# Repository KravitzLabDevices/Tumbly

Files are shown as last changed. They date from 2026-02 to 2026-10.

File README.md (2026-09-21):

# Tumbly
<p align="center">
  Tumbly timelapse
</p>
An Arduino library for the Tumbly device, a time-restricted feeding device. 

**Hardware:** Adafruit Feather M0, OLED FeatherWing (SH1107), RTC FeatherWing, SD card, Servo  

See the [Wiki](https://github.com/KravitzLabDevices/Tumbly/wiki) for build instructions.

Based on the [Tumble Feeder](https://pubmed.ncbi.nlm.nih.gov/40541188/).

## License

GPL-3.0

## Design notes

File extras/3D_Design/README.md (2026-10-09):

3D print the four .stl files in this folder (currently for Allentown MAX caging):  


Editable TinkerCAD design is [here](https://www.tinkercad.com/things/fWfIexFPPOE-tumblycurrent100926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).

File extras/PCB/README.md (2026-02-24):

Order the custom PCB (you can download BRD and SCH files from the extras directory and have this made anywhere, or click this link to order the PCB from OshPark)



Top  <br>

Bottom

Assembly instructions:  
1) Populate the custom PCB:  
  

2) Add stacking headers to the Adafruit DS3231 RTC board and Adafruit M0 Adalogger
  

3) Stack the four boards together - that's it!



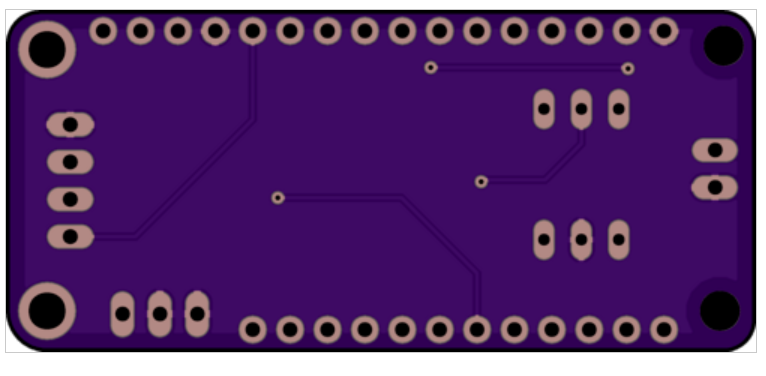
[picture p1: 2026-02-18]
extras/PCB/Bottom.png

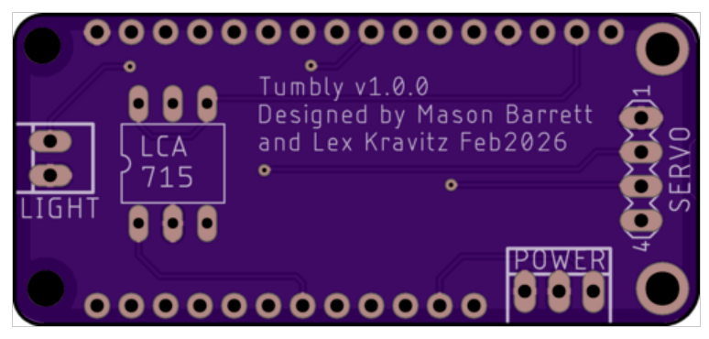
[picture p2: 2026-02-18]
extras/PCB/Top.png

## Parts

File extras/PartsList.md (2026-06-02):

## <a href="https://docs.google.com/spreadsheets/d/1O0kQEswAetQ5PXhv6P8ZYKxMUGYi77xnT9NAyXGhbck/edit?usp=sharing">Click here</a> for Tumbly parts list.
<br>
Updated 05/26/2026

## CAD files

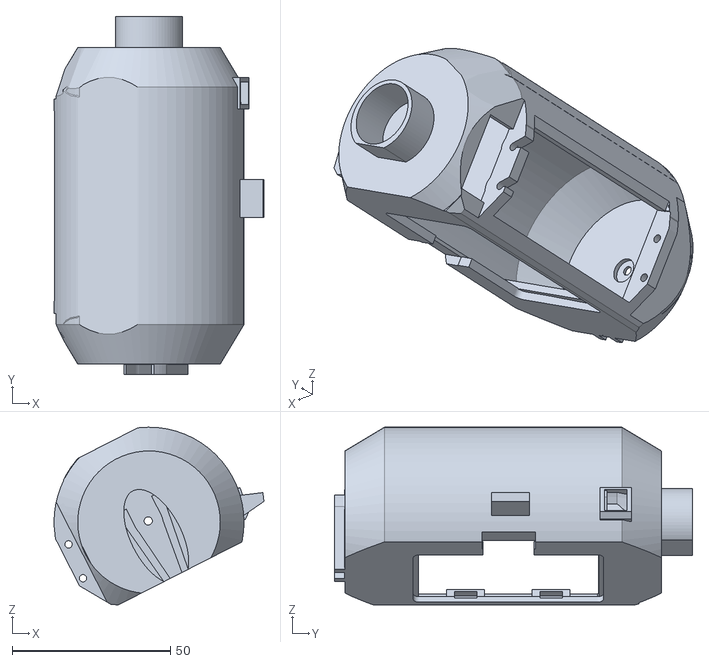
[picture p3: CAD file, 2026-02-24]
extras/3D_Design/Tumbly_Hopper.stl
66.3 x 113.1 x 56.1

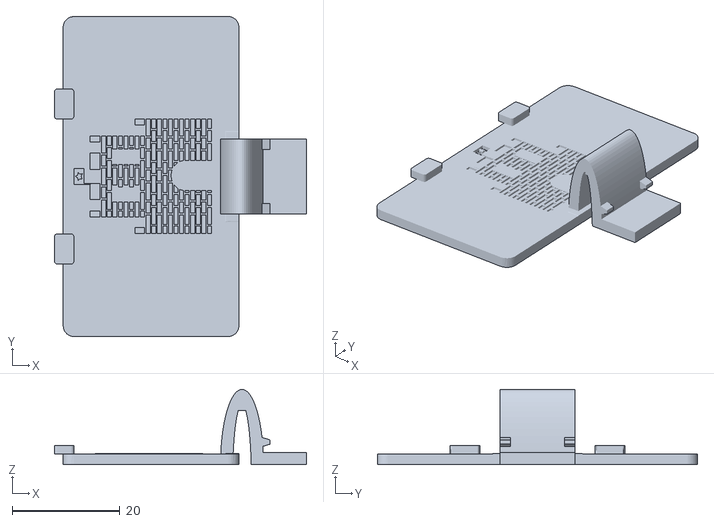
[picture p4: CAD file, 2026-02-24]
extras/3D_Design/Tumbly_Door.stl
46.9 x 59.5 x 14.0

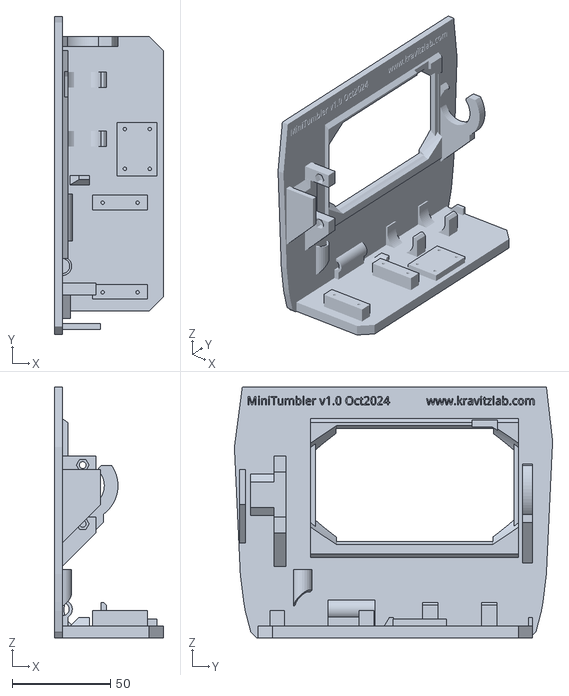
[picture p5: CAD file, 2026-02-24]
extras/3D_Design/Tumbly_Base.stl
55.5 x 162.3 x 128.0

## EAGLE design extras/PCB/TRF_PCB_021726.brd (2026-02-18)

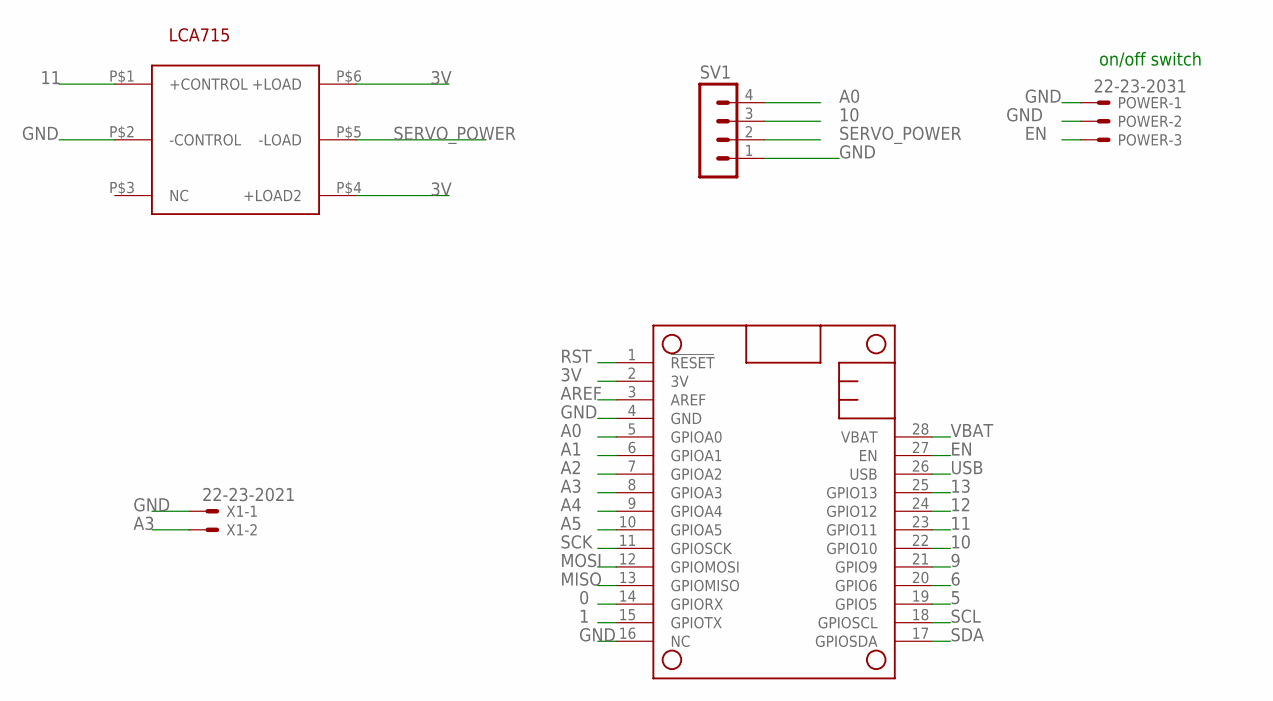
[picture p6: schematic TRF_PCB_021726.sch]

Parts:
MS2: MICROSHIELD_NODIM; MICROSHIELD_DIM
POWER: 22-23-2031
SSR3: LCA715S; LCA7XX
SV1: MA04-1
X1: 22-23-2021

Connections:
0: MS2.14 (GPIORX)
1: MS2.15 (GPIOTX)
3V: MS2.2 (3V), SSR3.P$4 (+LOAD2), SSR3.P$6 (+LOAD)
5: MS2.19 (GPIO5)
6: MS2.20 (GPIO6)
9: MS2.21 (GPIO9)
10: MS2.22 (GPIO10), SV1.3
11: MS2.23 (GPIO11), SSR3.P$1 (+CONTROL)
12: MS2.24 (GPIO12)
13: MS2.25 (GPIO13)
A0: MS2.5 (GPIOA0), SV1.4
A1: MS2.6 (GPIOA1)
A2: MS2.7 (GPIOA2)
A3: MS2.8 (GPIOA3), X1.2
A4: MS2.9 (GPIOA4)
A5: MS2.10 (GPIOA5)
AREF: MS2.3 (AREF)
EN: MS2.27 (EN), POWER.3
GND: MS2.4 (GND), MS2.16 (NC), POWER.1, POWER.2, SSR3.P$2 (-CONTROL), SV1.1, X1.1
MISO: MS2.13 (GPIOMISO)
MOSI: MS2.12 (GPIOMOSI)
RST: MS2.1 (!RESET)
SCK: MS2.11 (GPIOSCK)
SCL: MS2.18 (GPIOSCL)
SDA: MS2.17 (GPIOSDA)
SERVO_POWER: SSR3.P$5 (-LOAD), SV1.2
USB: MS2.26 (USB)
VBAT: MS2.28 (VBAT)

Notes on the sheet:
on/off switch

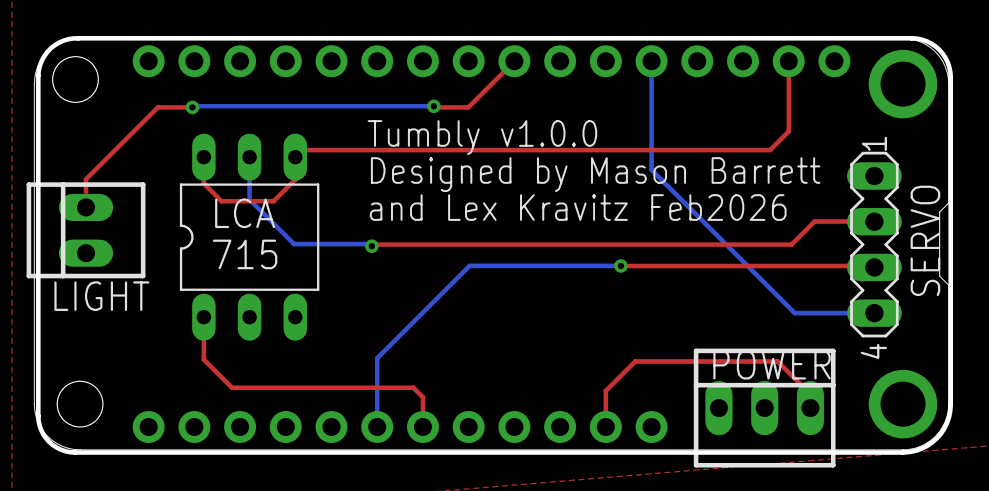
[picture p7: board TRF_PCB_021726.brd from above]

Board: 2 copper layers, 50.7 x 23.0 mm, 5 parts (0 on the bottom side), 8 nets.

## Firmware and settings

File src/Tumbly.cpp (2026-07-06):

/********************************************************
  Tumbly - Library
  Copyright (c) 2024 Lex Kravitz, Mason Barrett
  Released under GPL-3.0
 ********************************************************/

#include "Tumbly.h"
#include <math.h>

/*==============================================================================
  STARTUP ANIMATION
  File-scope drawing helpers for the boot animation (a mouse tipping a "TUMBLY"
  block into a cage of food). Not part of the class API. Coordinates assume the
  128x64 landscape orientation set up in begin().
==============================================================================*/

// Scatter of food pellets piled in the bottom-left corner.
static void _animFood(Adafruit_SH1107& d) {
  d.fillCircle( 7,62,3,SH110X_WHITE); d.fillCircle(16,63,3,SH110X_WHITE);
  d.fillCircle(25,61,3,SH110X_WHITE); d.fillCircle(34,63,3,SH110X_WHITE);
  d.fillCircle(42,62,3,SH110X_WHITE); d.fillCircle(11,55,3,SH110X_WHITE);
  d.fillCircle(21,54,3,SH110X_WHITE); d.fillCircle(30,56,3,SH110X_WHITE);
  d.fillCircle(39,54,3,SH110X_WHITE); d.fillCircle(15,48,3,SH110X_WHITE);
  d.fillCircle(26,47,3,SH110X_WHITE); d.fillCircle(36,49,2,SH110X_WHITE);
  d.fillCircle(19,41,3,SH110X_WHITE); d.fillCircle(29,40,2,SH110X_WHITE);
  d.fillCircle(24,35,2,SH110X_WHITE);
}

// Cage bars; cellY slides the cage in vertically during the animation.
static void _animCell(Adafruit_SH1107& d, int cellY) {
  int boxTop    = max(cellY, 0);
  int boxBottom = min(cellY + 43, 63);
  if (boxBottom < boxTop) return;
  if (cellY >= 0 && cellY <= 61)
    d.fillRect(2, cellY, 46, 3, SH110X_WHITE);
  int barXs[] = {2, 13, 24, 35, 46};
  int barLen  = boxBottom - boxTop + 1;
  for (int i = 0; i < 5; i++) {
    d.drawFastVLine(barXs[i],     boxTop, barLen, SH110X_WHITE);
    d.drawFastVLine(barXs[i] + 1, boxTop, barLen, SH110X_WHITE);
  }
}

// The mouse; ox shifts it horizontally so it can walk in from the right.
static void _animMouse(Adafruit_SH1107& d, int ox) {
  // Body — scanline horizontal ellipse
  { const int ecx=95+ox, ecy=60, ra=17, rb=9;
    for (int y=max(0,ecy-rb); y<=min(63,ecy+rb); y++) {
      float dy=(float)(y-ecy);
      int   dx=(int)(ra*sqrtf(1.0f-(dy*dy)/((float)(rb*rb))));
      d.drawFastHLine(ecx-dx, y, 2*dx+1, SH110X_WHITE);
    }
  }
  d.fillCircle(81+ox,50,7,SH110X_WHITE);                          // head
  d.fillCircle(86+ox,43,4,SH110X_WHITE);                          // ear
  d.fillTriangle(68+ox,50,74+ox,46,74+ox,54,SH110X_WHITE);        // nose
  d.fillCircle(82+ox,47,2,SH110X_BLACK);                          // eye
  d.drawLine(71+ox,49,63+ox,45,SH110X_WHITE);                     // whiskers
  d.drawLine(71+ox,51,62+ox,51,SH110X_WHITE);
  d.drawLine(71+ox,53,63+ox,57,SH110X_WHITE);
  { const int tcx=115+ox, tcy=59, tr=9;                           // tail arc
    for (int a=180; a>0; a-=15) {
      float r1=a*3.14159265f/180.0f, r2=(a-15)*3.14159265f/180.0f;
      d.drawLine(tcx+(int)(tr*cosf(r1)+0.5f), tcy-(int)(tr*sinf(r1)+0.5f),
                 tcx+(int)(tr*cosf(r2)+0.5f), tcy-(int)(tr*sinf(r2)+0.5f),
                 SH110X_WHITE);
    }
  }
}

// The "TUMBLY" text block rendered from a 1-bit canvas; startX slides it in and
// a small per-row lean gives it a tipping look.
static void _animTumbly(Adafruit_SH1107& d, GFXcanvas1& canvas, int startX) {
  if (startX >= 128) return;
  for (int cy=0; cy<20; cy++) {
    int lean=(5*max(0,16-cy))/16;
    for (int cx=0; cx<96; cx++) {
      if (canvas.getPixel(cx,cy)) {
        int dx=startX+cx+lean;
        if (dx>=0 && dx<128) d.drawPixel(dx, cy, SH110X_WHITE);
      }
    }
  }
  int ls=max(0,startX);
  d.drawFastHLine(ls,  0, 128-ls, SH110X_WHITE);
  d.drawFastHLine(ls, 20, 128-ls, SH110X_WHITE);
}

// Compose one full frame from the four elements and push it to the panel.
static void _animFrame(Adafruit_SH1107& d, GFXcanvas1& canvas, int tx, int cy, int mx) {
  d.clearDisplay();
  _animFood(d); _animCell(d,cy); _animMouse(d,mx); _animTumbly(d,canvas,tx);
  d.display();
}

// Play the whole sequence: block slides in, mouse tips it, it falls and bounces.
static void _animPlay(Adafruit_SH1107& d) {
  GFXcanvas1 canvas(96, 20);
  canvas.fillScreen(0); canvas.setTextSize(2);
  canvas.setTextColor(1); canvas.setCursor(2,2);
  canvas.print("TUMBLY");
  delay(100);

  _animFrame(d,canvas,128,-50,128); delay(200);
  _animFrame(d,canvas, 95,-50,128); delay(250);
  _animFrame(d,canvas, 75,-50,128); delay(250);
  _animFrame(d,canvas, 62,-50,128); delay(250);
  _animFrame(d,canvas, 50,-50,128); delay(200);

  _animFrame(d,canvas,50,-50, 50); delay(115);
  _animFrame(d,canvas,50,-41, 25); delay(100);
  _animFrame(d,canvas,50,-29,  0); delay(80);
  _animFrame(d,canvas,50,-14,  0); delay(60);
  _animFrame(d,canvas,50,  2,  0); delay(42);
  _animFrame(d,canvas,50, 13,  0); delay(30);
  _animFrame(d,canvas,50, 19,  0); delay(22);
  _animFrame(d,canvas,50, 21,  0); delay(18);  // slam!
  _animFrame(d,canvas,50, 14,  0); delay(65);  // bounce
  _animFrame(d,canvas,50, 21,  0); delay(55);
  _animFrame(d,canvas,50, 17,  0); delay(50);
  _animFrame(d,canvas,50, 21,  0); delay(100); // hold
}

/*==============================================================================
  STATIC STATE & CALLBACKS
  A single active instance pointer lets the C-style RTC/wake callbacks reach the
  object. _wokenByButton is set from the sleep wake interrupt.
==============================================================================*/

static Tumbly* _instance = nullptr;
static bool _wokenByButton = false;

// Sleep wake-on-button interrupt handler.
static void wakeupCallback() { _wokenByButton = true; }

// SdFat calls this to stamp files with the current RTC time.
static void _dateTimeCallback(uint16_t* date, uint16_t* time) {
  DateTime now = _instance->rtc.now();
  *date = FAT_DATE(now.year(), now.month(), now.day());
  *time = FAT_TIME(now.hour(), now.minute(), now.second());
}

/*==============================================================================
  CONSTRUCTOR
==============================================================================*/

Tumbly::Tumbly(String& task, bool darkMode) : display(SCREEN_HEIGHT, SCREEN_WIDTH, &Wire), task(task), darkMode(darkMode) {}

/*==============================================================================
  LIFECYCLE
==============================================================================*/
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

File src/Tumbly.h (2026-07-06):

/********************************************************
  Tumbly - Library
  Time-restricted feeding with OLED display and SD logging
  Copyright (c) 2024 Lex Kravitz, Mason Barrett
  Released under GPL-3.0
 ********************************************************/

#ifndef TUMBLY_H
#define TUMBLY_H

/*==============================================================================
  DEPENDENCIES
  Target hardware: Adafruit Feather M0 (SAMD21) + OLED FeatherWing (SH1107),
  DS3231 RTC, microSD, and a feedback (analog-position) hobby servo.
==============================================================================*/

#include <Arduino.h>
#include <Servo.h>
#include "ArduinoLowPower.h"   // LowPower.sleep + wake-on-button interrupt
#include "RTClib.h"            // DS3231 real-time clock
#include <SdFat.h>             // SD logging + config file
#include <Wire.h>
#include <Adafruit_GFX.h>
#include <Adafruit_SH110X.h>   // 128x64 OLED

/*==============================================================================
  PIN MAP & DISPLAY CONSTANTS
  The three front buttons are referred to two ways in the code: by physical
  letter (A/B/C) and by the on-screen color convention (RED/GREEN/BLUE).
==============================================================================*/

#define BUTTON_A      9
#define BUTTON_B      6
#define BUTTON_C      5
#define RED_BUTTON    BUTTON_A   // increment / start / "A"
#define GREEN_BUTTON  BUTTON_B   // decrement / resume / "B"
#define BLUE_BUTTON   BUTTON_C   // select / edit / next / "C"
#define SERVO_FEEDBACK A0        // analog position feedback from the servo pot

#define SCREEN_WIDTH  128
#define SCREEN_HEIGHT 64

class Tumbly {
public:
  /*----------------------------------------------------------------------------
    LIFECYCLE
    begin() runs once (calibration, config, animation). run() is the main loop
    body: one wake cycle (sensors -> door logic -> log -> display -> sleep).
  ----------------------------------------------------------------------------*/
  Tumbly(String& task, bool darkMode = false);

  void begin();
  void run();

  /*----------------------------------------------------------------------------
    OPERATIONAL STEPS (called from run(), exposed for flexibility)
  ----------------------------------------------------------------------------*/
  void ReadSensors();          // light + battery
  void TimedDoor();            // open/close by time-of-day window (task 0)
  void LightControlledDoor();  // open/close by ambient light
  void LogData();              // append one CSV row to the SD log
  void UpdateDisplay();        // draw the status screen
  void GoToSleep();            // low-power sleep until next cycle / button wake
  void open_door();            // drive servo to the OPEN feedback target
  void close_door();           // drive servo to the CLOSED feedback target

  /*----------------------------------------------------------------------------
    USER CONFIG (persisted to config.txt)
  ----------------------------------------------------------------------------*/
  int   deviceId      = 1;
  int   taskIndex     = 0;     // 0 TimedDoor, 1 FreeFeeding, 2 Demo
  int   openHour        = 20;
  int   closeHour       = 4;
  int   openMinute      = 0;
  int   closeMinute     = 0;
  int   openpos      = 0;      // legacy position fields (kept for config compat)
  int   closedpos    = 0;
  int   feedbackOpen    = -1;  // ADC target for the OPEN position (-1 = uncalibrated)
  int   feedbackClosed  = -1;  // ADC target for the CLOSED position
  int   sleeptime    = 30;     // seconds per wake cycle

  /*----------------------------------------------------------------------------
    RUNTIME STATE
  ----------------------------------------------------------------------------*/
  bool  sdPresent     = true;
  int   lux          = 0;
  bool  doorOpen     = true;
  char  filename[30];
  float measuredvbat = 0;
  int   feedbackTolerance = 50;  // +/- ADC counts still considered "on target"
  int   lastFeedback    = -1;    // -1 means "not measured this cycle"
  bool  servoError      = false;
  String lastError      = "OK";
  bool   demoMode       = false;
  bool   darkMode       = false;
  String task;

  /*----------------------------------------------------------------------------
    HARDWARE OBJECTS
  ----------------------------------------------------------------------------*/
  RTC_DS3231      rtc;
  Servo           myservo;
  File            logfile;
  Adafruit_SH1107 display;
  SdFat           SD;

private:
  static constexpr int _chipSelect = 4;

  // Debounced button state, refreshed by readButtons().
  bool          _redTouch   = false;
  bool          _greenTouch = false;
  bool          _blueTouch  = false;
  unsigned long _menustart  = 0;
  bool          _endstate   = false;  // signals an Edit* screen to exit

  /*----------------------------------------------------------------------------
    INTERNAL HELPERS
  ----------------------------------------------------------------------------*/
  void readButtons();
  void beep();

  // Settings menu + calibration screens
  void SettingsMenu();
  void EditTask();
  void EditDeviceId();
  void EditOpenHour();
  void EditCloseHour();
  void EditOpenPosition();
  void EditClosedPosition();

  // SD helpers
  void writeHeader();
  void saveConfig();
  bool loadConfig();
  void error();

  // Servo feedback + position verification
  int  readFeedback();
  void HourlyCheck();
  void shakeServo();
  void FatalServoError();

  /*----------------------------------------------------------------------------
    INTERNAL STATE (not user-configurable)
  ----------------------------------------------------------------------------*/
  int  _wakeCount       = 0;
  int  _lastPWM         = 90;   // last commanded servo angle
  int  _openPWM         = 90;   // servo angle that last matched feedbackOpen
  int  _closedPWM       = 90;   // servo angle that last matched feedbackClosed
  int  _demoPhaseCount  = 0;
  bool _demoClosedPhase = true;
  bool _darkActive      = false;  // display temporarily woken in dark mode
  bool _fatalActive     = false;  // latched servo-error state (resume with B)
};

#endif

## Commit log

2026-02-18 Add PCB design and Arduino firmware files
    Add complete Eagle PCB files and board images plus the Arduino firmware source. Files added: extras/PCB (TRF_PCB_021726.brd, .sch, Top.png, Bottom.png) and src/*.ino modules (Battery, Display, Door, 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
    [TRF_PCB_021726.brd, TRF_PCB_021726.sch]
2026-02-18 Refactor into Tumbly Arduino library
    Merge legacy INO sketches into a proper Arduino library: add src/Tumbly.cpp and src/Tumbly.h with a public API (begin, run, setDeviceId, setSleepTime, setDoorTimes, setDoorPositions, and helpers). Ad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
2026-02-24 Add 3D design STLs and PCB README extras
    Add 3D printing assets and documentation for the Tumbly project: three STL files (Tumbly_Base.stl, Tumbly_Door.stl, Tumbly_Hopper.stl) under extras/3D_Design and README.md files for extras/3D_Design 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
    [Tumbly_Base.stl, Tumbly_Door.stl, Tumbly_Hopper.stl]
2026-02-24 Update README for clarity on 3D printing files
2026-02-24 Revise PCB README with ordering details and images
    Updated README to include ordering information and images.
2026-02-24 Update README with PCB assembly instructions
    Added instructions for populating the custom PCB and stacking headers.
2026-02-24 Update assembly instructions in README.md
2026-02-24 Adjust image sizes and formatting in README.md
    Updated image sizes in PCB assembly instructions and added line breaks.
2026-02-24 Enhance README with images for PCB assembly steps
    Added images to the README for better visualization of the PCB stacking process.
2026-04-16 UI and settings improvements
    Fixed door close time off-by-1 hour. Light sensor now logs and displays "Light"/"Dark" instead of raw values. Settings menu no longer auto-starts — requires button press. Added device ID editor to settings flow. Replaced open/close time editors with an interactive 24-hour timeline. Servo open position minimum corrected to 0.
    [Tumbly.cpp, Tumbly.h, Tumbly.ino]
2026-04-16 Config saving, SD enforcement, wake fix, FreeFeeding task
    Device now saves and loads settings from config.txt on the SD card. SD card is required to start. Wake button works reliably every sleep cycle. Added FreeFeeding task with on-device task selection.
    [Tumbly.cpp, Tumbly.h]
2026-10-12 Add low-battery shutdown protection
    This adds a low-voltage safety cutoff that stops all activity when the battery drops below 3.5V. The code averages multiple ADC samples before checking the battery, logs a final LOW_BATTERY row, powers down the display and servo, and then enters a low-power loop that only blinks the red onboard LED every 2 seconds until the device is recharged and reset.
